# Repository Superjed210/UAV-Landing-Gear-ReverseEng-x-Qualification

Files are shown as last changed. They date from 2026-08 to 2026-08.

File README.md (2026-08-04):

<p align="center">
  <a>
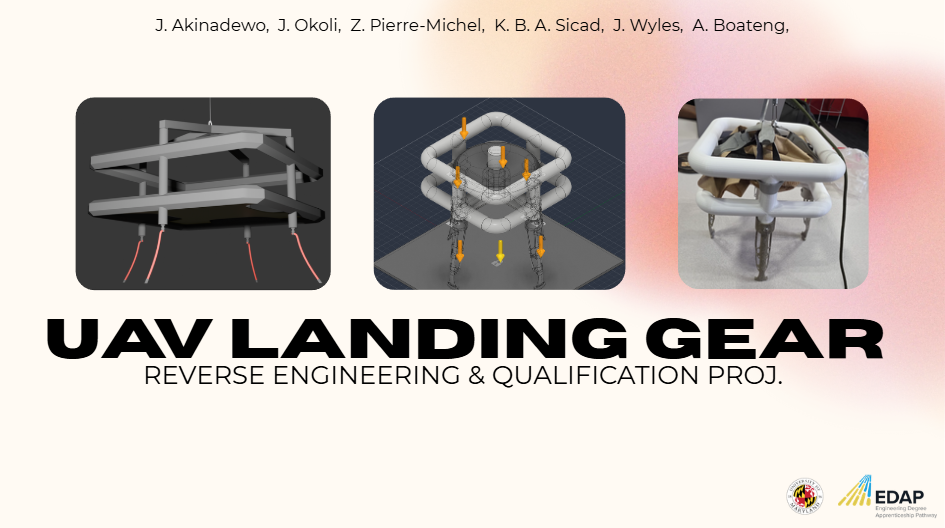
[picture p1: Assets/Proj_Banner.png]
Project Banner
    
  </a>
</p>

> University of Maryland – Department of Materials Science & Engineering
> 
> Summer 2026 - Engineering Design & Additive Manufacturing Research Internship Through *Growth Sector's EDAP Program*

---

## Overview

This repository documents an eight-week engineering research internship completed with the University of Maryland Department of Materials Science & Engineering.

The project followed the complete engineering design process to reverse engineer, digitally reconstruct, optimize, manufacture, and qualify an existing unmanned aerial vehicle (UAV) landing leg. The original component lacked engineering documentation, requiring the team to recover its geometry through metrology, evaluate its structural performance through computational modeling, redesign the component for improved performance and manufacturability, fabricate prototypes using multiple additive manufacturing processes, and validate the final designs through experimental testing.

Rather than focusing on a single engineering discipline, the project integrated reverse engineering, CAD reconstruction, finite element analysis, topology optimization, additive manufacturing, embedded systems, experimental testing, and engineering documentation into one continuous workflow.

---

## Project Background

Mechanical components frequently require replacement long after the original design documentation has been lost or becomes unavailable. In many cases, replacement parts must not only replicate the original geometry but also improve manufacturability, structural performance, and overall efficiency.

To simulate this engineering challenge, the internship used the landing foot from a 2 kg UAV as a case study. The project provided an opportunity to apply the engineering design process from initial inspection through final qualification while maintaining the intended functionality of the original component.

---

## Case Study

The selected engineering challenge involved the qualification of a UAV landing foot intended for a 2kg quadcopter.

The landing gear was expected to:
- Support takeoff and landing
- Perform across multiple landing surfaces including concrete, *(exp: soil, grass, pavement)*
- Protect onboard electronics during impact
- Maintain structural integrity
- Remain economical to manufacture

---

## Engineering Workflow

The complete workflow followed throughout the internship is shown below.

```text
Existing Part
      │
      ▼
Reverse Engineering
      │
      ▼
3D Scanning & Metrology
      │
      ▼
CAD Reconstruction
      │
      ▼
Design Evaluation
      │
      ▼
Topology Optimization
      │
      ▼
Hybrid Design Development
      │
      ▼
Computational Modeling
      │
      ▼
Additive Manufacturing
      │
      ▼
Instrumentation
      │
      ▼
Experimental Testing
      │
      ▼
Qualification
```

Each stage informed the next, allowing engineering decisions to be supported by measured data instead of assumptions.

---

## Reverse Engineering

The project began with reverse engineering an existing UAV landing foot.

Using the Hexagon Romer Absolute Arm, the physical component was digitized into a high-resolution mesh. The resulting scan data was processed in Geomagic Design X to remove imperfections, extract geometric features, and reconstruct an editable CAD model suitable for engineering analysis and manufacturing.

### Primary Tools

- Hexagon Romer Absolute Arm
- Geomagic Design X
- Autodesk Fusion 360

---

## Design and Optimization

Following reconstruction, the landing foot underwent multiple design iterations focused on improving structural performance while minimizing unnecessary material.

Optimization techniques included:

- Static stress analysis
- Shape optimization
- Generative design
- Hybrid optimization

Rather than selecting a purely topology-optimized solution, the final design combined the structural efficiency of topology optimization with the manufacturable geometry of the selected generative design. :contentReference[oaicite:6]{index=6}

---

## Computational Modeling

Finite element analysis was used to evaluate both the original and optimized landing leg designs.

The project progressed from static structural analysis toward dynamic event modeling to better represent transient impact events encountered during landing.

Simulation development included:

- Static stress analysis
- Dynamic event modeling
- Custom nonlinear material definition
- Stress-strain curve development for LPBF 316L stainless steel
- Impact simulations at multiple drop heights

Simulation parameters included:

- Material: 316L Stainless Steel
- Drop heights: 0.15 m, 0.30 m, 0.50 m
- Rigid impact surface
- Gravity enabled
- Structural constraints
- Separated contact conditions

---

## Additive Manufacturing

Multiple additive manufacturing technologies were explored throughout the project.

### PETG Prototype

- Material: PETG
- Process: FDM
- Printer: Bambu Lab X1 Carbon
- Layer Height: 0.16 mm
- Gyroid infill

### Nylon Prototype

- Material: Nylon 12
- Process: Selective Laser Sintering (SLS)

### Metal Prototype

- Material: Stainless Steel
- Process: Laser Powder Bed Fusion (LPBF)

These manufacturing methods allowed comparison between polymer prototypes and production-capable metal components.

---

## Embedded Instrumentation

A custom embedded data acquisition system was developed to characterize landing performance during experimental testing.

Primary components included:

- ESP32 Microcontroller
- ADXL375 High-G Accelerometer
- VL53L1X Time-of-Flight Distance Sensor

The instrumentation system measured:

- Free-fall duration
- Landing velocity
- Peak acceleration
- Bounce height
- Distance from ground
- Structural response during impact

Sensor communication utilized the I²C protocol and calibration routines were implemented prior to testing to reduce measurement error.

## Experimental Testing

Prototype qualification consisted of controlled drop testing.

Testing incorporated:

- Custom drop rig
- Camera tracking
- Embedded sensors
- Multiple landing surfaces
- Graphical data analysis
- Visual inspection

Drop tests were conducted on:
- Concrete
- Soil

using multiple drop heights to evaluate structural behavior under different impact conditions.

## Key Results

Highlights from the project include:

- Successful digital reconstruction of the original UAV landing foot
- Development of a manufacturable hybrid optimized design
- Integration of computational modeling and physical testing
- Custom nonlinear material modeling for 316L stainless steel simulations
- Embedded instrumentation for experimental qualification
- Peak acceleration reduction of approximately **62%** at a 0.5 m drop height
- Maximum yielding reported at approximately **10.1%** during evaluation

---

## Skills Demonstrated

This project demonstrates experience in:

- Engineering Design Process
- Reverse Engineering
- Metrology
- CAD Reconstruction
- Fusion 360
- Geomagic Design X
- Finite Element Analysis
- Dynamic Event Simulation
- Topology Optimization
- Generative Design
- Design for Additive Manufacturing
- Experimental Design
- Data Acquisition
- Sensor Calibration
- ESP32 Embedded Systems
- Engineering Documentation
- Technical Communication

---

## Repository Structure

```text
assets/
data/
docs/
firmware/
models/
references/
presentation/
```

Additional documentation for each engineering phase can be found within the corresponding directories.

---

## Personal Contributions

During this internship, I contributed to multiple phases of the engineering workflow, including CAD reconstruction, computational modeling, design optimization, embedded instrumentation, firmware development, sensor calibration, experimental testing, data analysis, and technical documentation.

This repository serves as a technical record of that work and highlights the interdisciplinary engineering skills developed throughout the internship.

---

## Repository purpose

This repository is intended for educational and professional portfolio purposes.

Some proprietary design files, datasets, or laboratory resources may not be included.

---

## Acknowledgements

This work was completed through the Engineering Design and Additive Manufacturing Program (EDAP) hosted at the University of Maryland Department of Materials Science & Engineering in collaboration with Growth Sector.

Special thanks to the faculty, researchers, graduate students, and fellow interns whose mentorship and collaboration contributed to the success of this project.

---

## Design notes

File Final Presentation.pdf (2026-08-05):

# MSE Drone Leg Qualification

J. Akinadewo, J. Okoli, Z. Pierre-Michel, K. B. A. Sicad, J. Wyles, A. Boateng, and B. Daheu

## Problemstatement

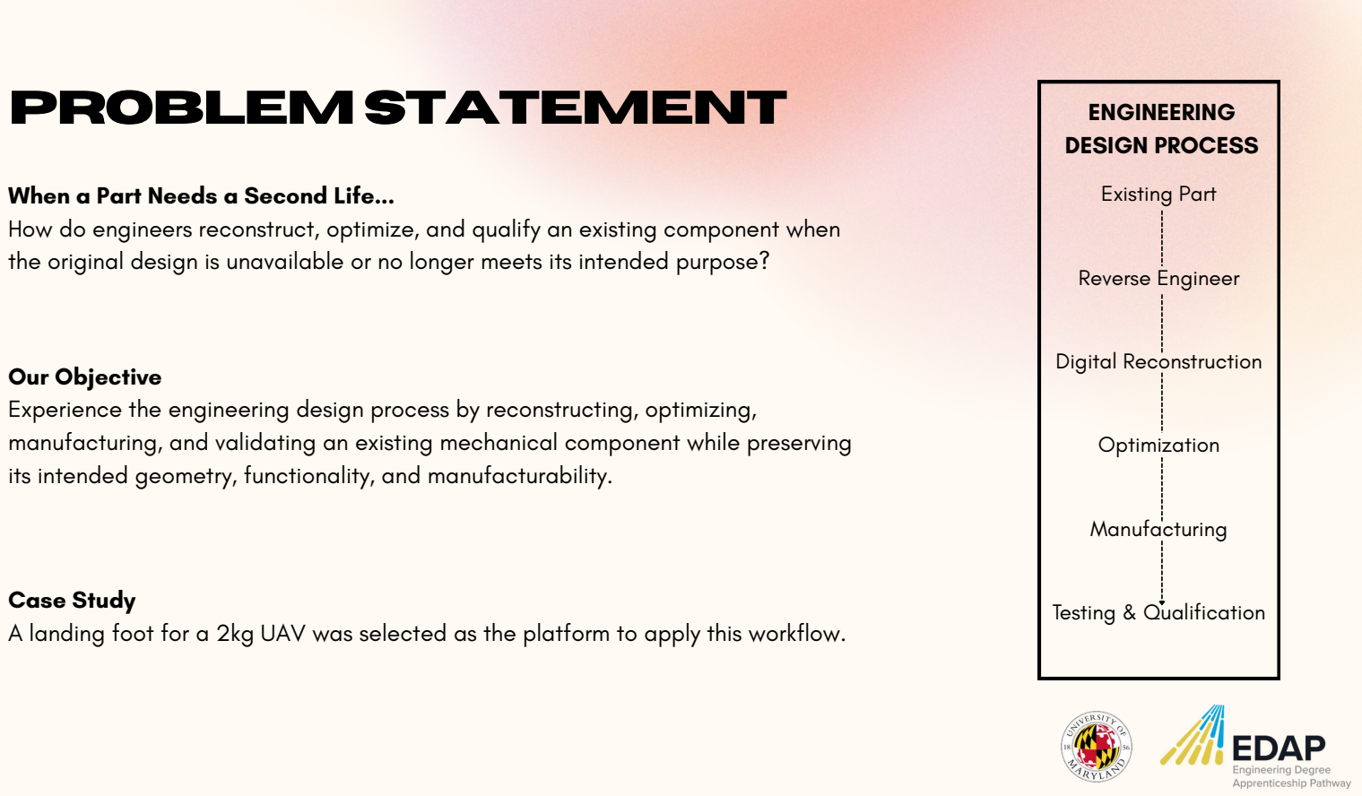
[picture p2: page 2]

Existing Part

Reverse Engineer

Digital Reconstruction

Optimization

Manufacturing

Testing & Qualification

When a Part Needs a Second Life...
How do engineers reconstruct, optimize, and qualify an existing component when the original design is unavailable or no longer meets its intended purpose?

ENGINEERING
DESIGN PROCESS

Our Objective
Experience the engineering design process by reconstructing, optimizing, manufacturing, and validating an existing mechanical component while preserving its intended geometry, functionality, and manufacturability.

Case Study
A landing foot for a 2kg UAV was selected as the platform to apply this workflow.

Concept
Apply the complete engineering design process to a challenge problem involving the reverse engineering & qualification of a UAV landing leg that requires reconstruction, optimization, and manufacturing.

## CASESTUDY

Important Factors
Support takeoff and landing in varied landing conditions (e.g., grass, Soil, Concrete) Ensure onboard packages remain safe on a heavy impact
Economical production while maintaining structural integrity
Achieve through metrology, design, manufacturing, and testing

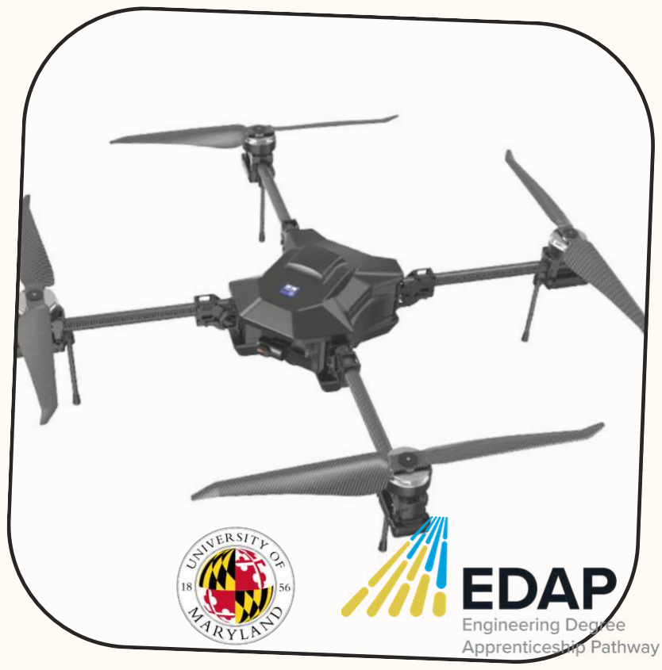
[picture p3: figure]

# Metrology

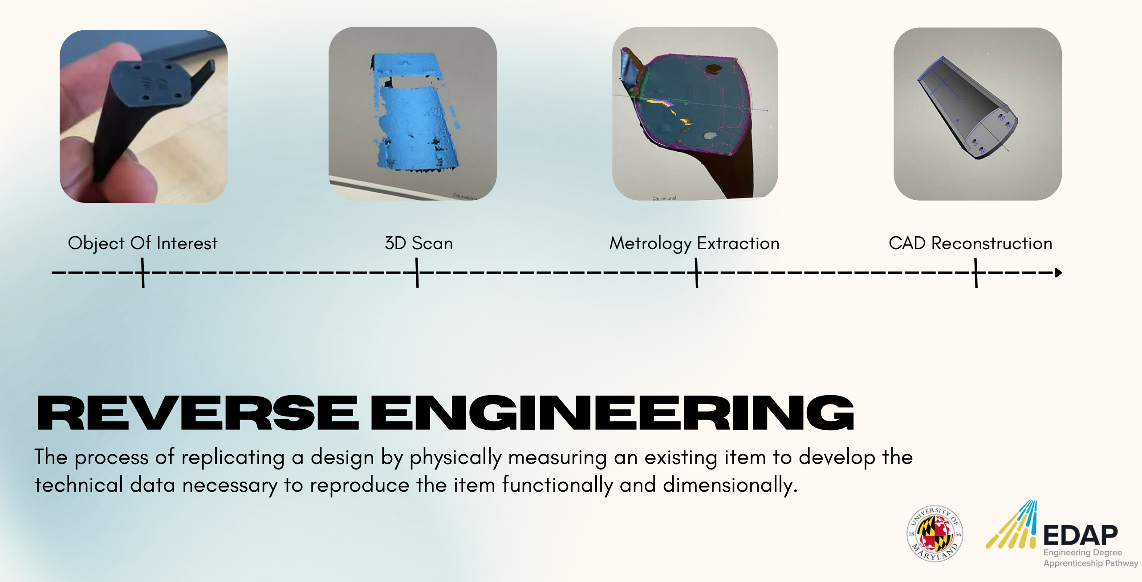
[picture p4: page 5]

Object Of Interest | 3D Scan | Metrology Extraction | CAD Reconstruction

The process of replicating a design by physically measuring an existing item to develop the technical data necessary to reproduce the item functionally and dimensionally.

# ReverseEngineering

## 3DScanning

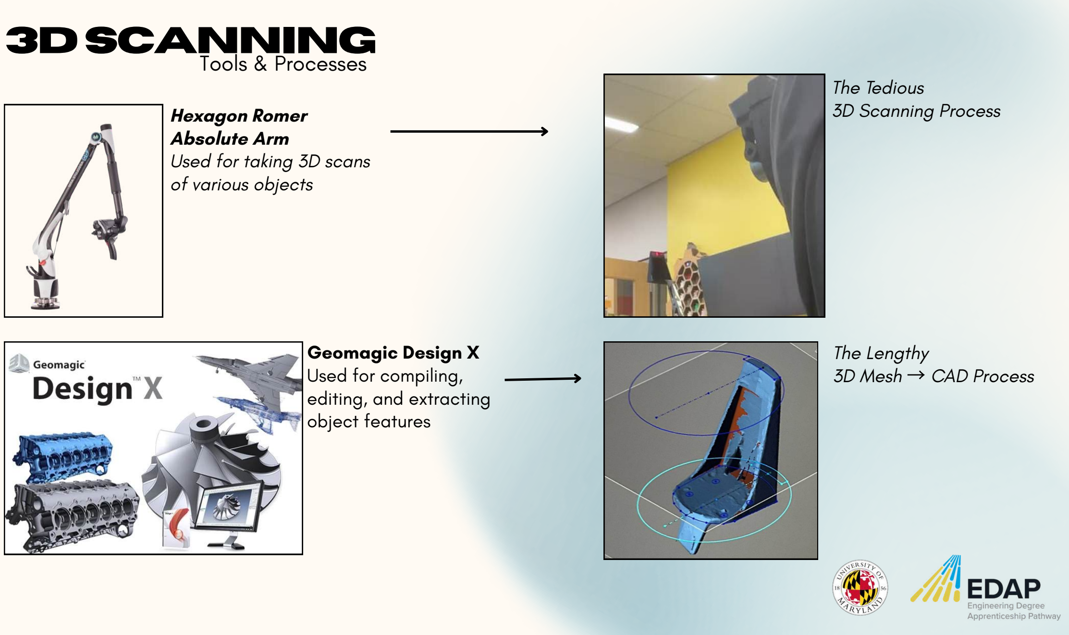
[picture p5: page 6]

Tools & Processes

Hexagon Romer
Absolute Arm
Used for taking 3D scans
of various objects

Geomagic Design X
Used for compiling,
editing, and extracting
object features

The Tedious
3D Scanning Process

The Lengthy
3D Mesh → CAD Process

# Design

## CHassisdesign

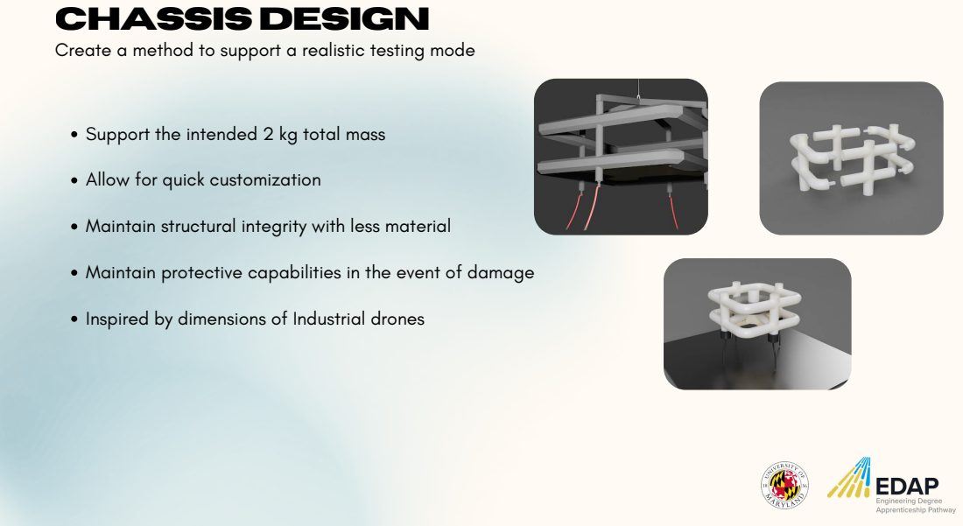
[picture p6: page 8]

Create a method to support a realistic testing mode

Support the intended 2 kg total mass

Allow for quick customization

Maintain structural integrity with less material

Maintain protective capabilities in the event of damage

Inspired by dimensions of Industrial drones

## iterativedesign

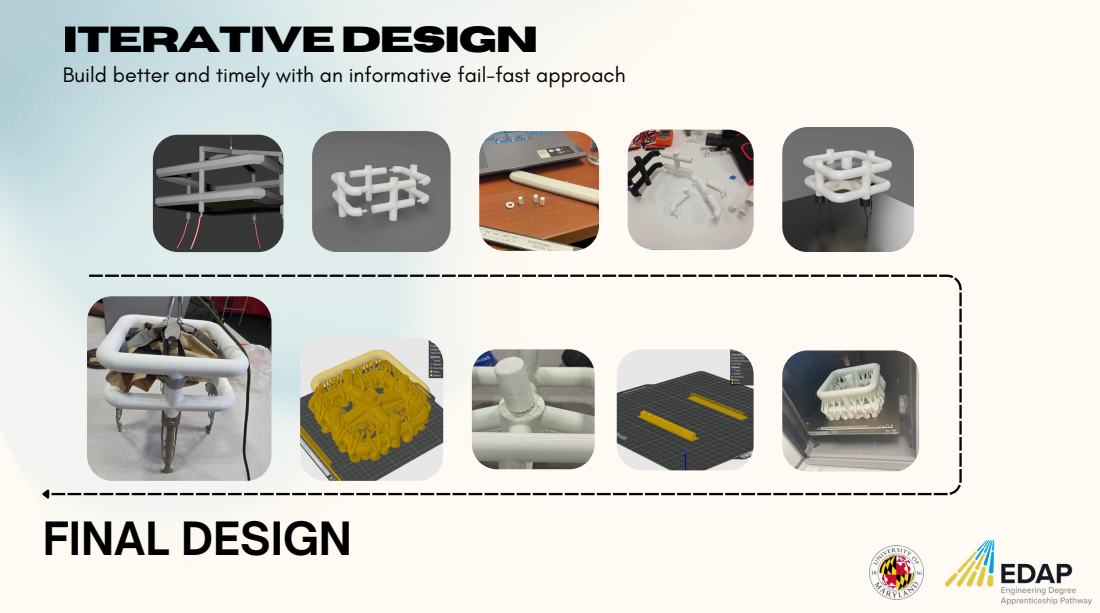
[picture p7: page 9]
FINAL DESIGN

Build better and timely with an informative fail-fast approach

# Design Experimentation

### What is a Charpy Test?

### This is an impact test used in materials

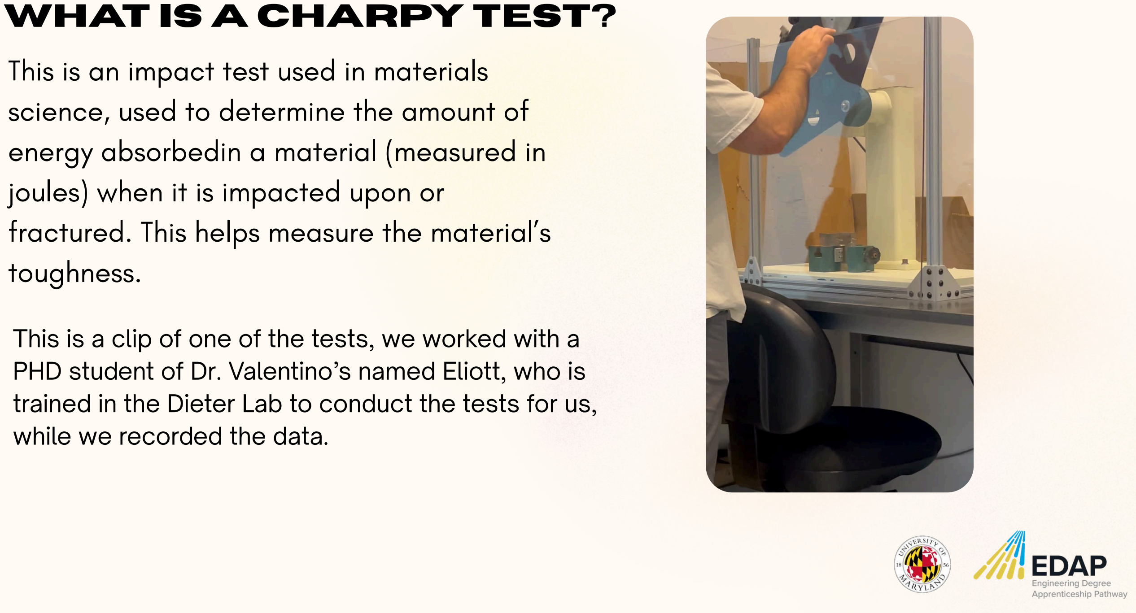
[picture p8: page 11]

### science, used to determine the amount of energy absorbedin a material (measured in joules) when it is impacted upon or fractured. This helps measure the material’

s
toughness.

This is a clip of one of the tests, we worked with a PHD student of Dr. Valentino’s named Eliott, who is trained in the Dieter Lab to conduct the tests for us, while we recorded the data.

## Charpy Impact Test Results

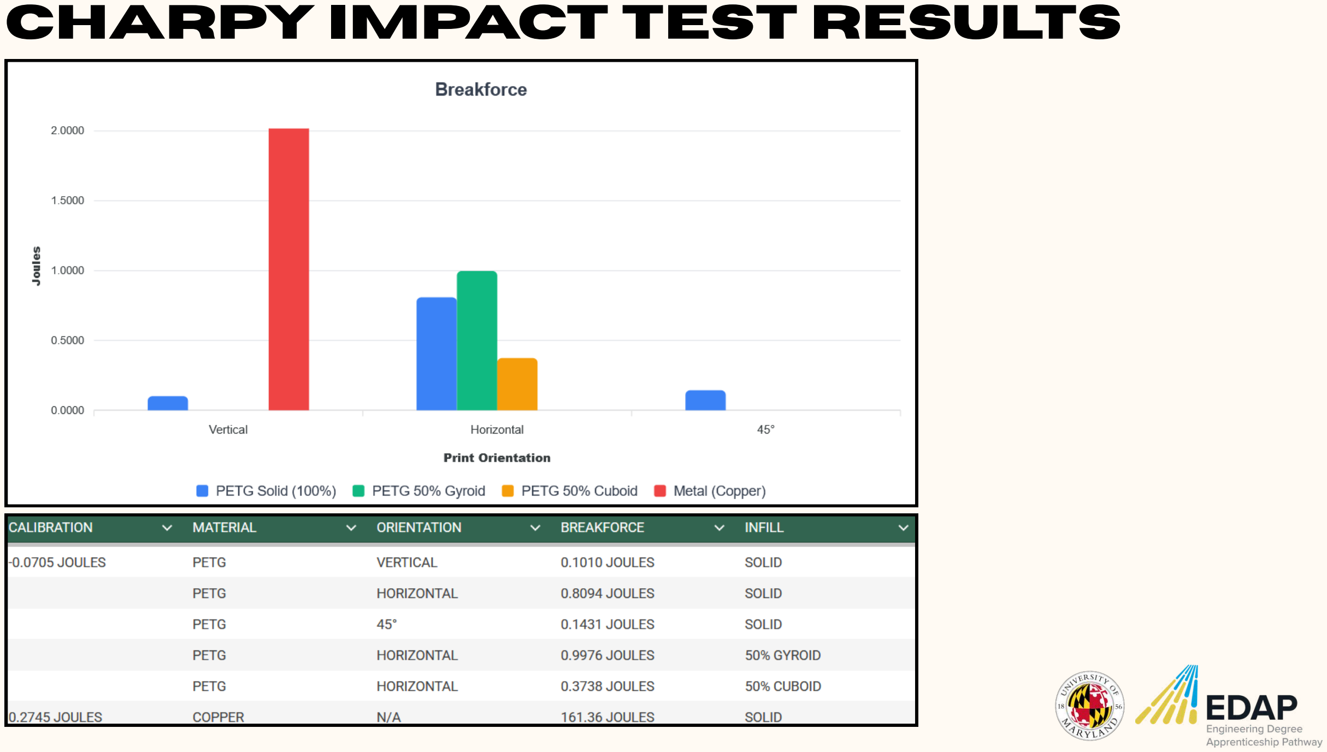
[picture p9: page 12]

## Legdesign

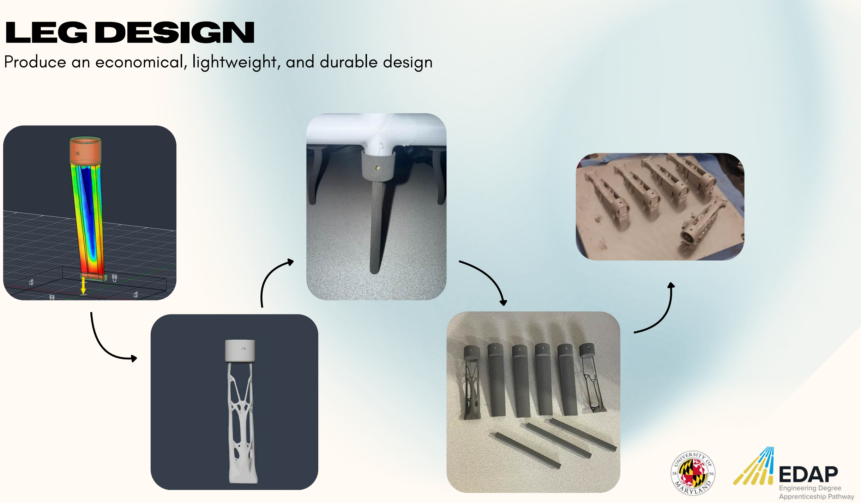
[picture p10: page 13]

Produce an economical, lightweight, and durable design

## ShapeOPtimization

## GenerativeDesign

Identifies the most efficient material distribution under the applied loads and constraints

Generates multiple manufacturable design concepts while preserving critical mounting regions.

## GenerativeDesign

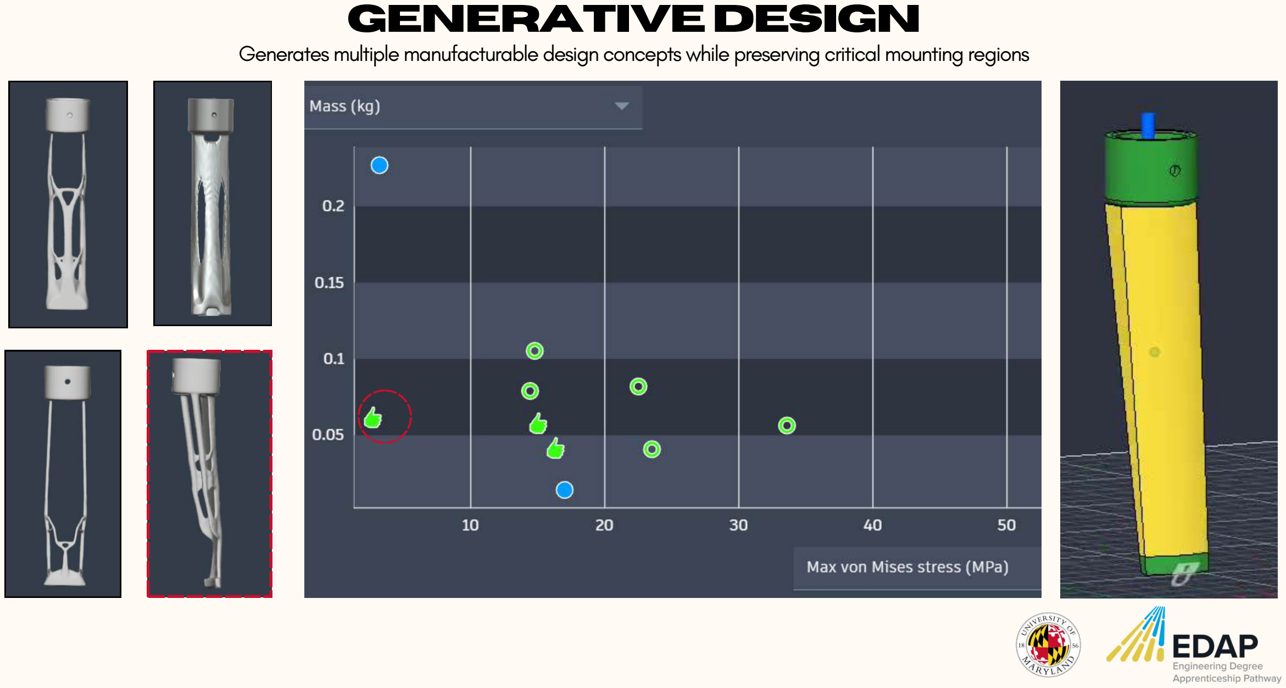
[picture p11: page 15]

Generates multiple manufacturable design concepts while preserving critical mounting regions

## HybridOPtimizedDesign

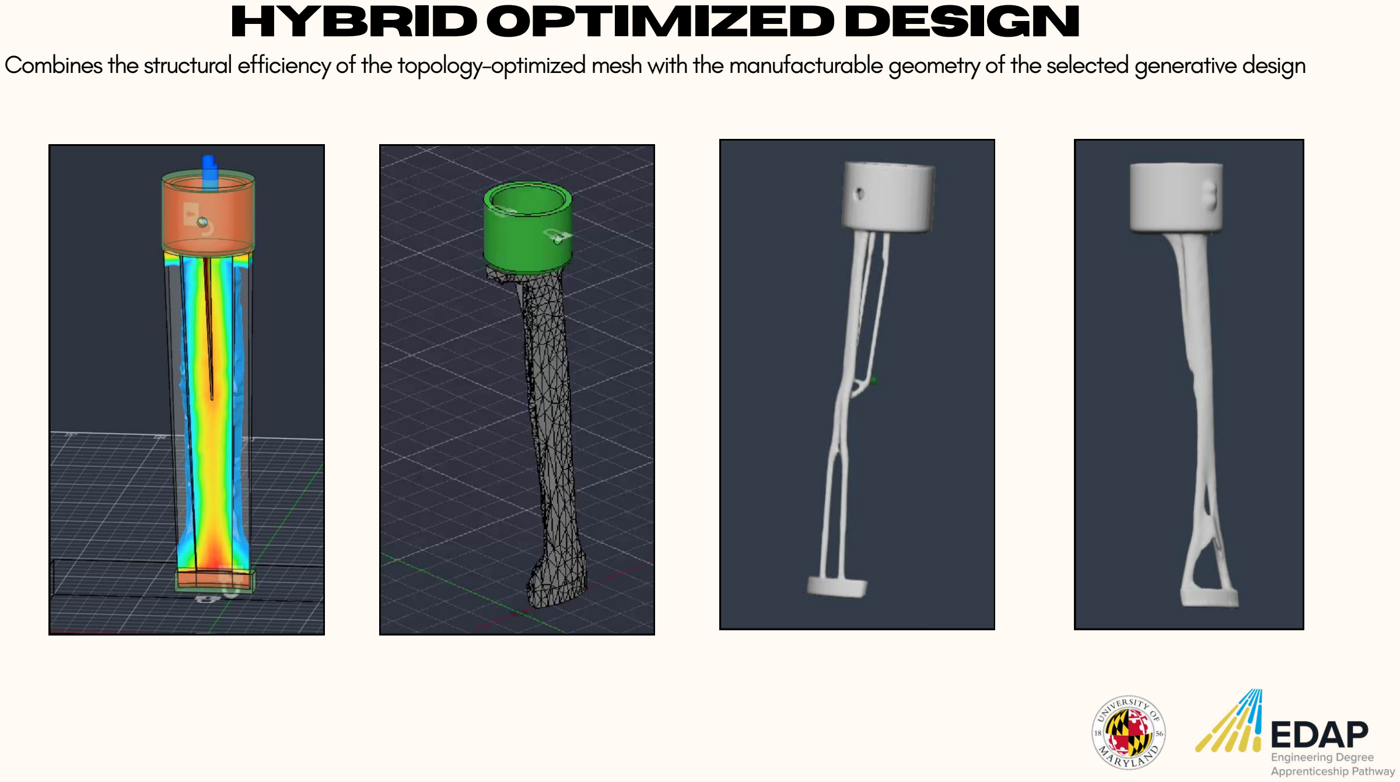
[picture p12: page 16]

Combines the structural efficiency ofthe topology-optimized mesh with the manufacturable geometry ofthe selected generative design

# Computational Modeling

## Staticstressmodeling

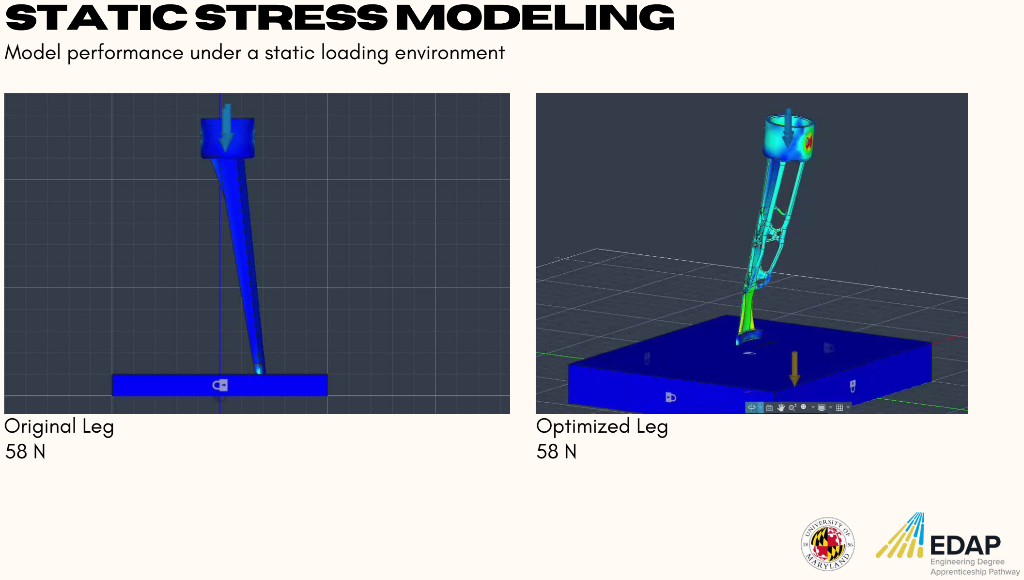
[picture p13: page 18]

Model performance under a static loading environment

Original Leg | Optimized Leg
58 N | 58 N

Dynamic Event | Static Stress
Analyzes short, fast, and violent events like crashes, drops, or hits. | Calculates safe loads, displacement, and stress under steady or slowly applied forces.
Accounts for mass, velocity, acceleration, inertia, and fast-changing contact between parts. | Ignores inertia, momentum, and acceleration because the load changes very little over time.
Requires non-linear stress-strain curve | Does not require stress-strain curve

## Dynamiceventmodeling

Transitioned from static stress analysis to a dynamic event simulation to capture transient force effects

Resolution: Sourced a peer-reviewed research paper containing empirical data detailing the exact stress-strain curves of SLM-printed SS316L.

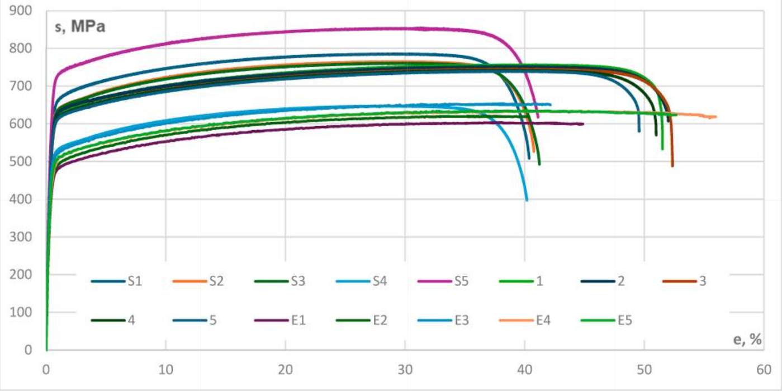
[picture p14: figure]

Sumanariu, Constantin Alex et al.“Comparative Analysis of Mechanical Properties: Conventional vs. Additive Manufacturing for Stainless Steel 316L.” Materials (Basel, Switzerland) vol. 17,19 4808. 29 Sep. 2024, doi:10.3390/ma17194808

## Datamodelingblocks

Autodesk Fusion

’

s default library lacks the non-linear stress-strain curve data required for Stainless Steel 316L impact simulations

## Dataextraction

Digitization

Data Conversion

CustomMaterial

True Strain Formula True Stress Formula

### Material: 316L Stainless Steel Drop Heights: 0.15m, 0.3m, and 0.5m Velocities: 1.72 m/s, 2.43 m/s, and 3.13 m/s

## Impact Surface: Rigid Floor

### Constraints: Structural Constraint

## Contacts: Separated Gravity: Enabled

## Technicalinformation

## Setup

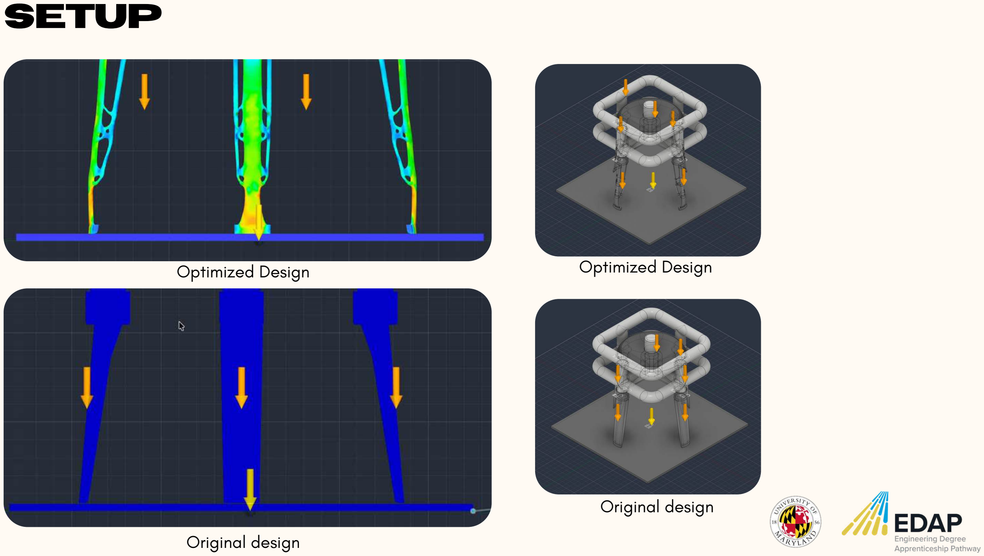
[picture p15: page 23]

Original design

Optimized Design

Original design

Optimized Design

A 62% reduction in Peak acceleration at 0.5 m

## Findings

10.1% Max Yielding

## Findings

# Electronics

## Keymetrics

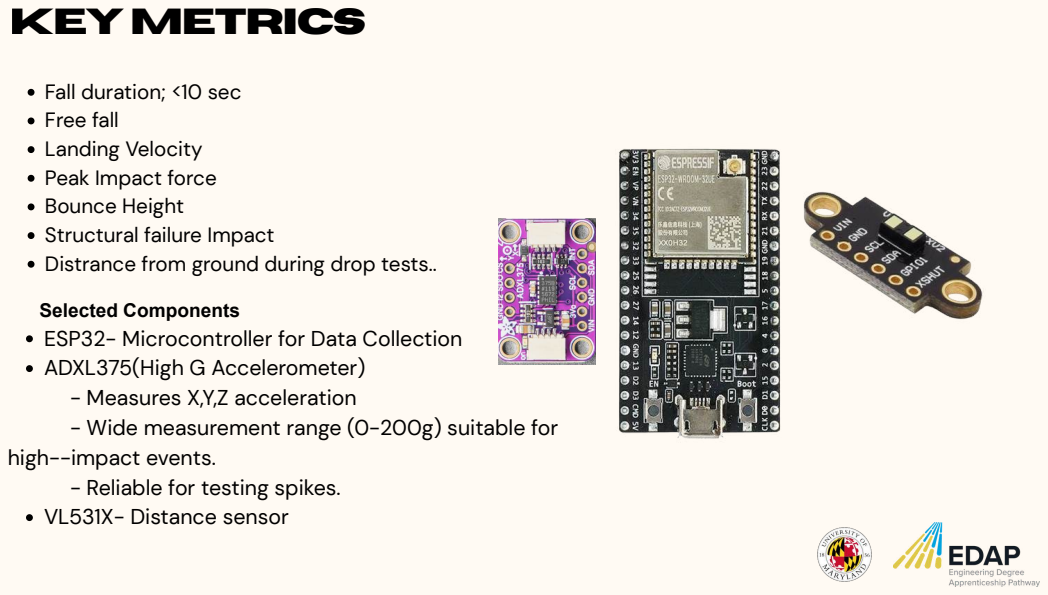
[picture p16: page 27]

Fall duration; <10 sec
Free fall
Landing Velocity
Peak Impact force
Bounce Height
Structural failure Impact
Distrance from ground during drop tests..

Selected Components
ESP32- Microcontroller for Data Collection
ADXL375(High G Accelerometer)
- Measures X,Y,Z acceleration
- Wide measurement range (0-200g) suitable for
high--impact events.
- Reliable for testing spikes.
VL531X- Distance sensor

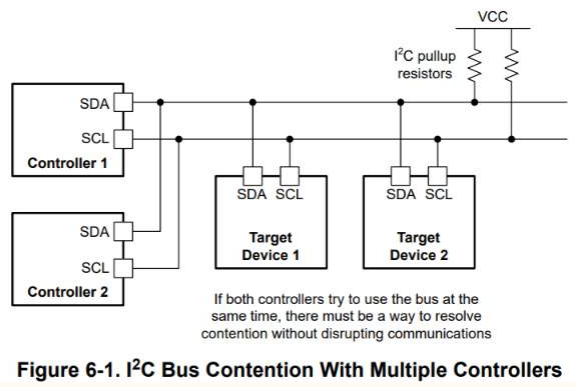
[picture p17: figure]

“3-Axis, ±200 G Digital MEMS Accelerometer.” n.d. Accessed July 30, 2026.

I2C (inter Integrated circuit) is a communication protocol that allows a microcontroller(master) communicate with multiple sensors (slave) using only two signal wires.

WHY we use I2C?
Built into the Arduino <Wire.h> Library
Multiple sensors share the same bread board bus. Uses only two communication wires.
SCL ⟶ Serial Clock synchronization
SDA ⟶ Data Transfer between ESP32 and sensors VIN/VCC ⟶ 3V or 5V
Reliable for real-time sensor measurements

Communication sequence
ESP32
Send Sensor REGISTERS/ADDRESS- Stores 8 bit data Sensor acknowledges (ACK)
Read/Write Register - //writeRegister(), //readRegister() Transfer Data/ Print
STOP

## esp32i2cComm

Sensor Calibration;
To improve mesaurement accurace, sensor offsets were calculated before testing;

Calibration Process

1.Calibrated distance sensor to zero out the baseline distance from the foot to the ground for precise measurements.

2.Calculated multiple stationary readings, Calculated the average X,Y, Z values. 3.Determined offset values using;
Offset = Measured Values - Value Average 4.Applied offsets in software to correct future measurements.

Results: Reduced errors and improved accuracy.

“3-Axis, ±200 G Digital MEMS Accelerometer.” n.d. Accessed July 30, 2026.

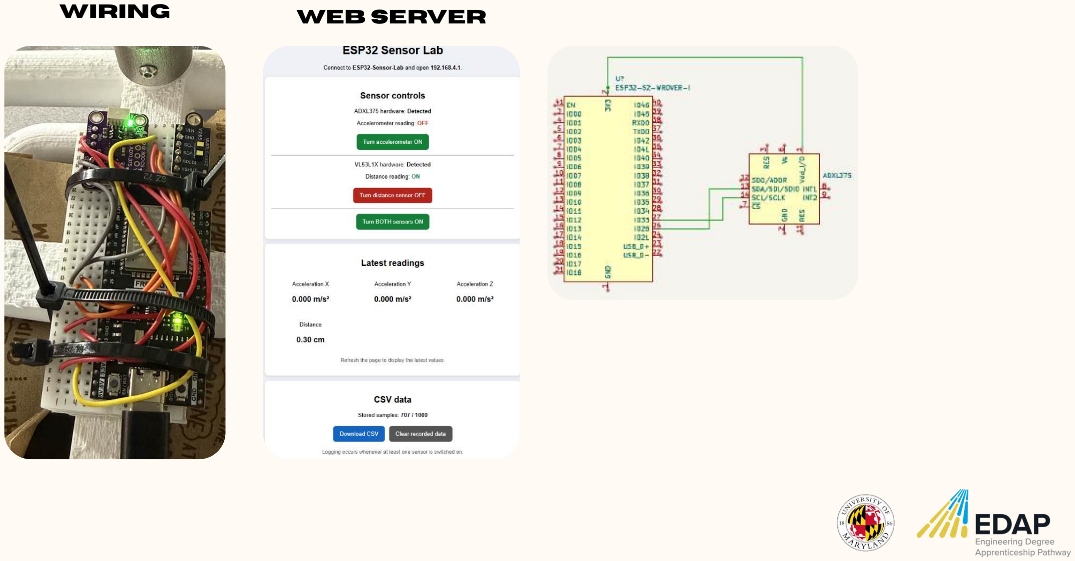
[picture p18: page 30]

Wiring | Web server

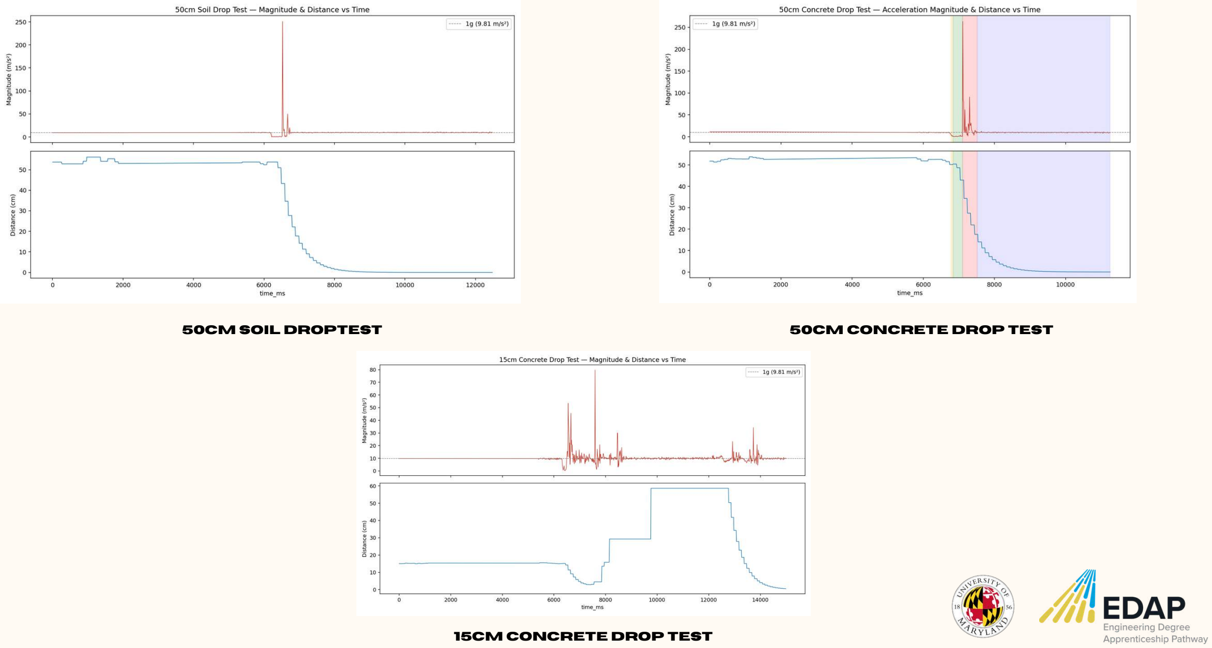
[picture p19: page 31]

50cmsoil droptest | 50cmconcrete drop test

15cmConcrete drop test

# Fabrication

# Rig Fabrication

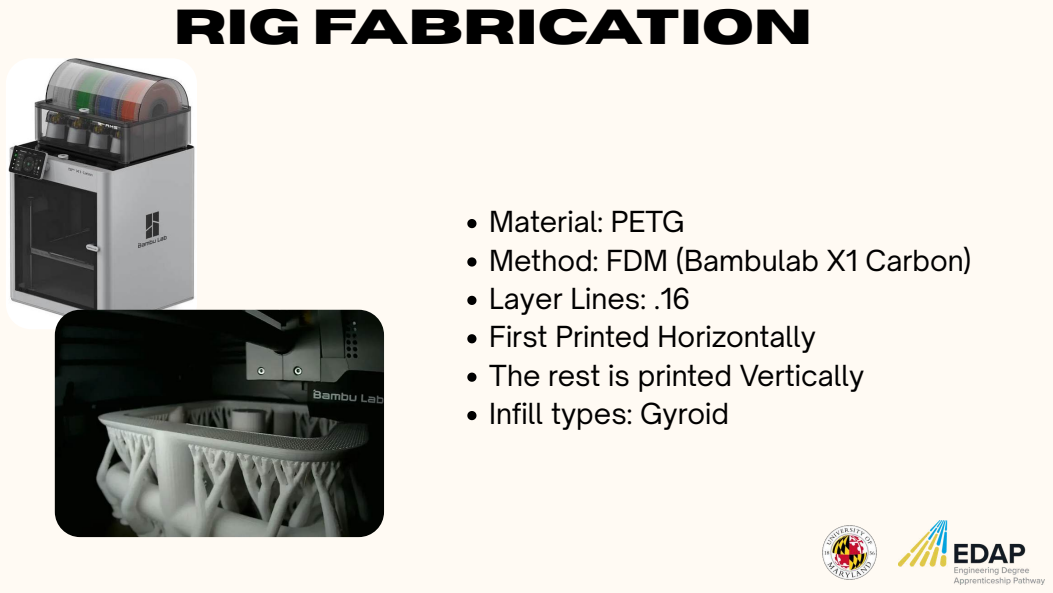
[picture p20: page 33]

Material: PETG
Method: FDM (Bambulab X1 Carbon)
Layer Lines: .16
First Printed Horizontally
The rest is printed Vertically
Infill types: Gyroid

# Nylon Foot Fabrication

## Material: Nylon 12 Method: SLS (Formlabs Fuse) Layer lines: Negligible more isotropic

# Steel Foot Fabrication

## Material: Steel Method: LPBF (EOS gmbh) Layer lines: Negligible more isotropic

# Post Processing

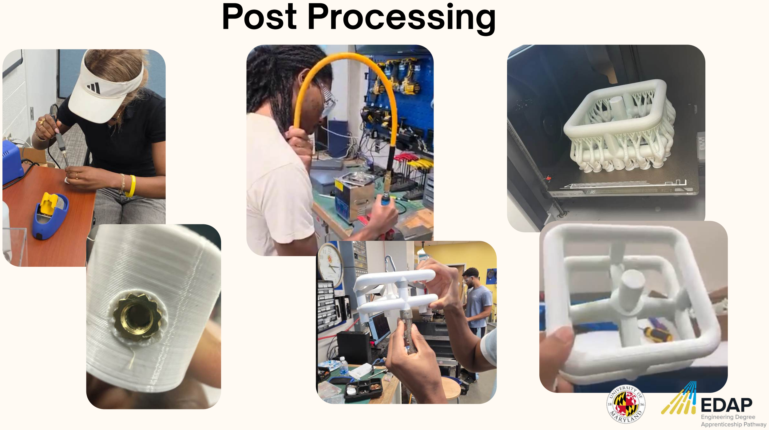
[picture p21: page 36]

# DROP TESTING

# Camera Tracking Electronics: Accelerometer and distance sensor

# Results

# Preparation and Setup

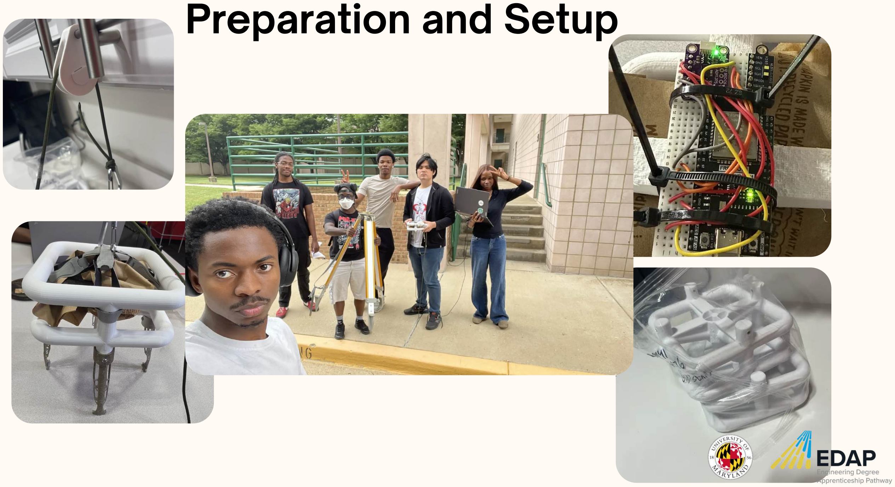
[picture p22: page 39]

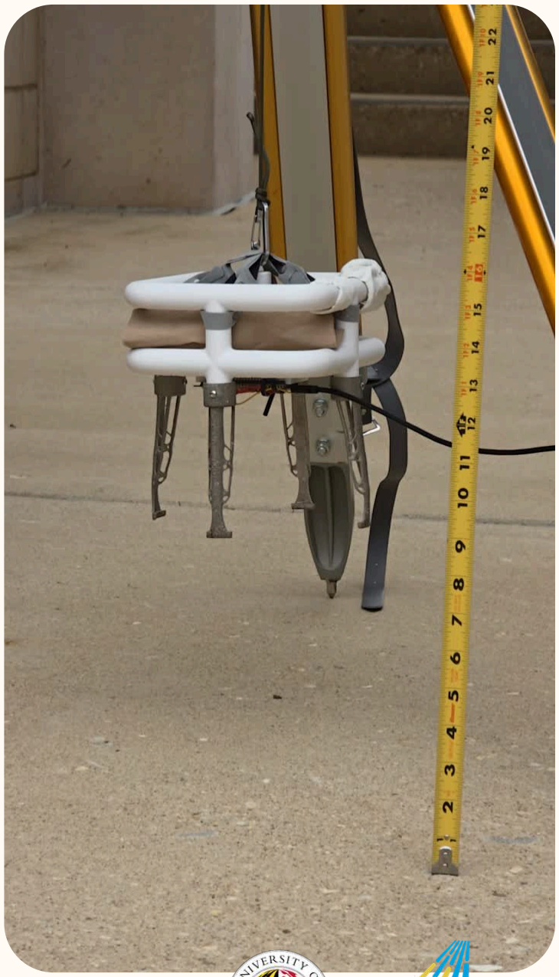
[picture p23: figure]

See in real time how different designs perform

## droptest

Coordinate group preparation

Release a complete model using a pulley

Gather visual and graphical data

Use gathered information to inform a conclusion

## Graphicaldata

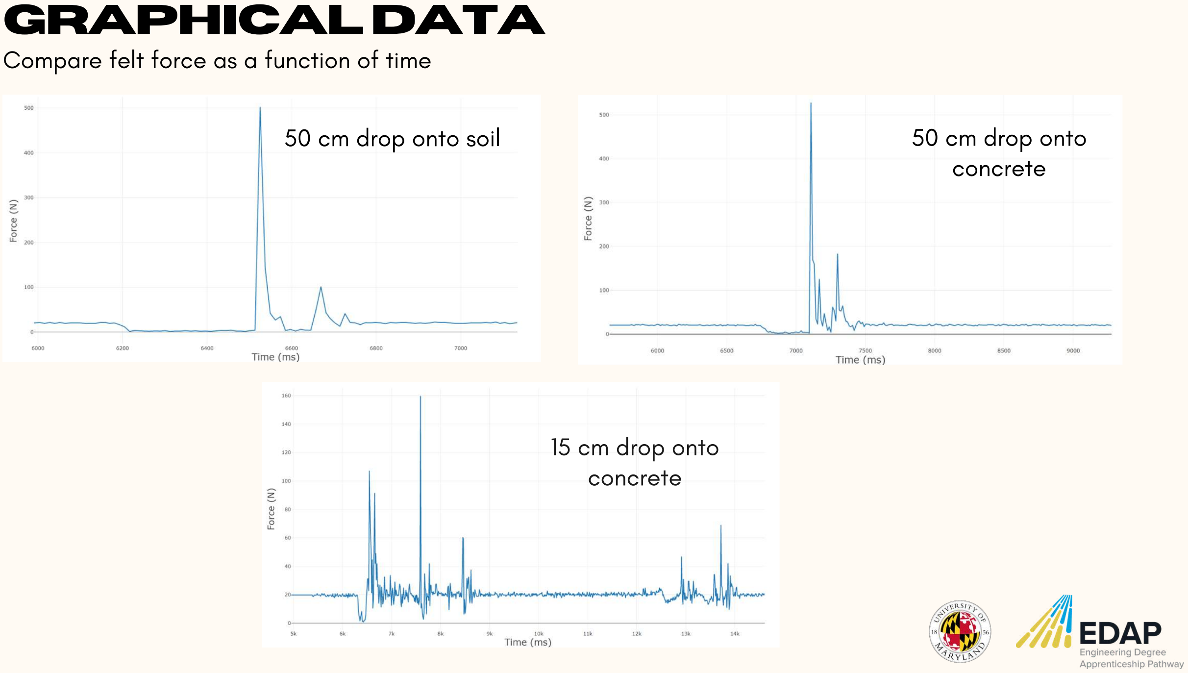
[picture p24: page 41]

Compare felt force as a function of time

50 cm drop onto soil

15 cm drop onto
concrete

50 cm drop onto
concrete

## Visualdata

Compare felt force as a function of time

50 cm drop onto soil

15 cm drop onto
concrete

50 cm drop onto
concrete

# Conclusion

# helpful LINKS

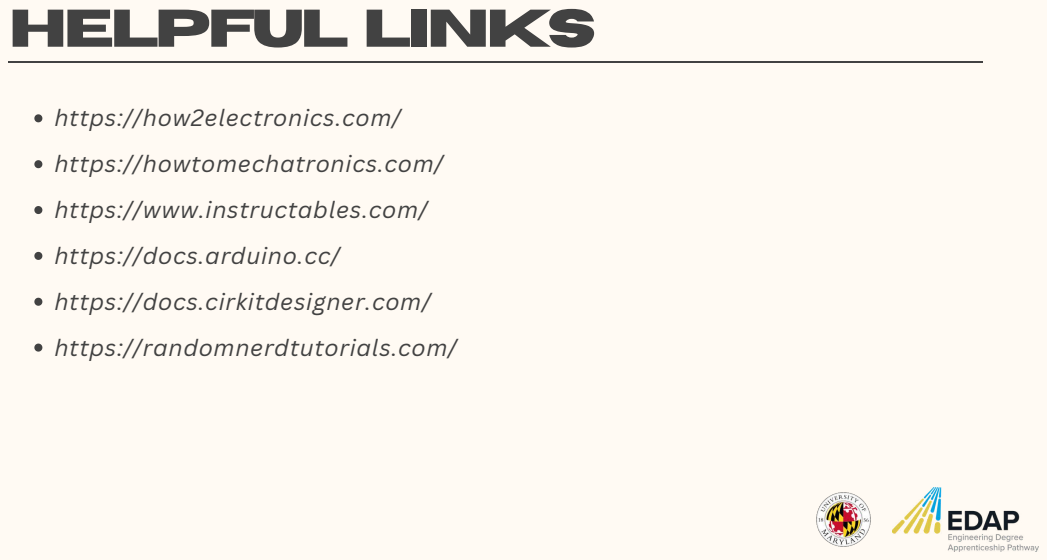
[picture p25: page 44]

https://how2electronics.com/
https://howtomechatronics.com/
https://www.instructables.com/
https://docs.arduino.cc/
https://docs.cirkitdesigner.com/
https://randomnerdtutorials.com/

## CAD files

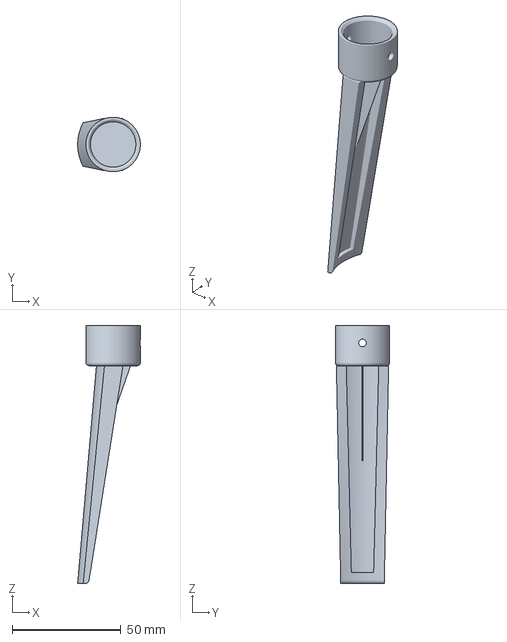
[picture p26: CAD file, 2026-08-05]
3D Models/Reinforced_Reference_Model.3mf
28.8 x 25.0 x 118.5 mm

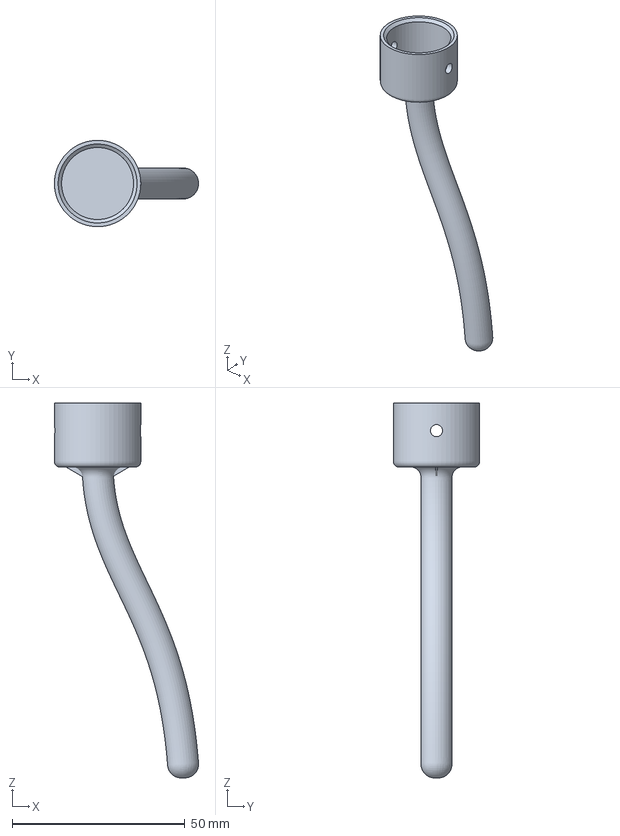
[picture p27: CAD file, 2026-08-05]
3D Models/spring-inspired-leg.3mf
41.7 x 25.0 x 108.5 mm

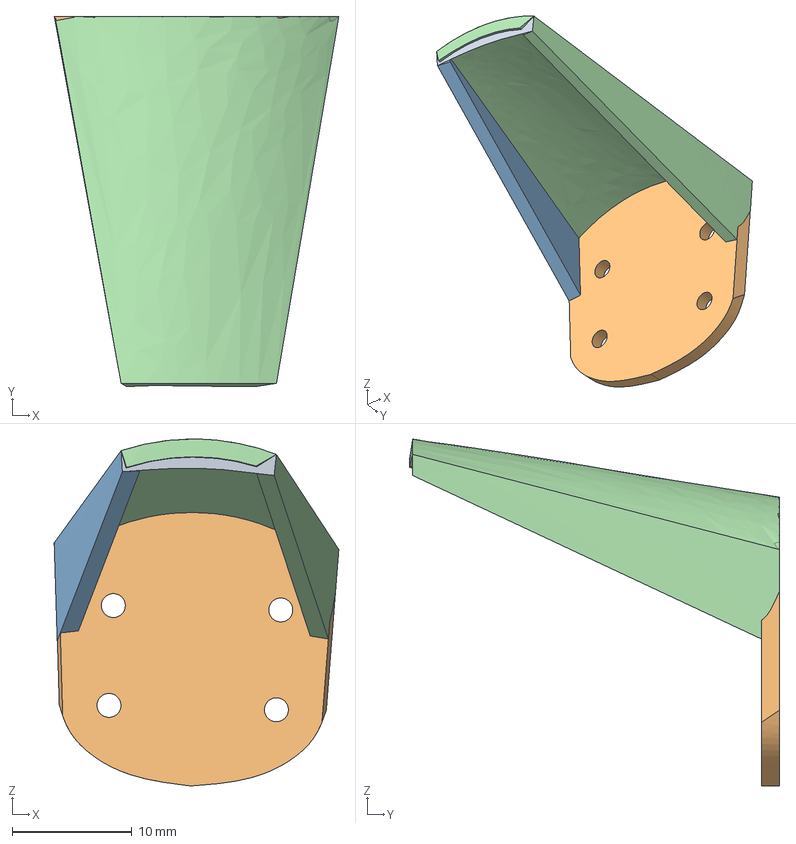
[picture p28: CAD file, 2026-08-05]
3D Models/Original_UAV_Landing_Leg.stp
23.8 x 30.9 x 29.0 mm

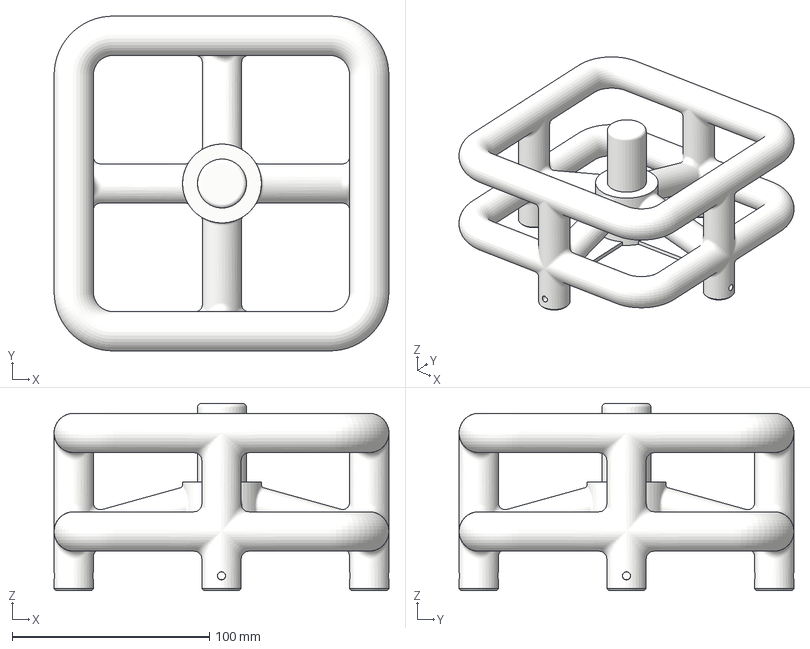
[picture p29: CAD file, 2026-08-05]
3D Models/Test_Rig.3mf
170.0 x 170.0 x 95.0 mm

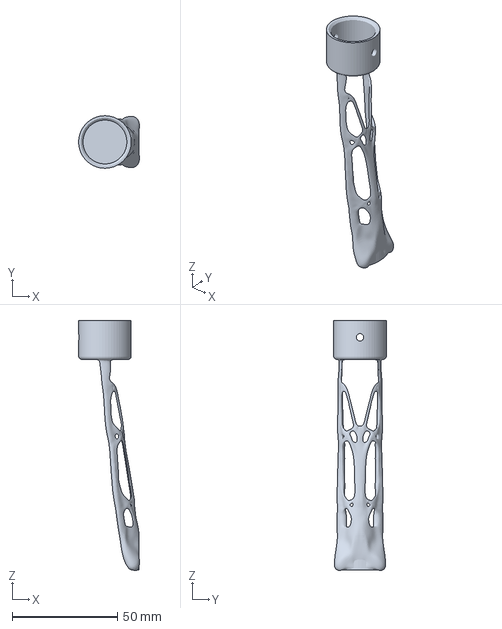
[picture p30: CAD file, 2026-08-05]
3D Models/Iteration_01_Dual_Strut.3mf
28.9 x 25.0 x 118.8 mm

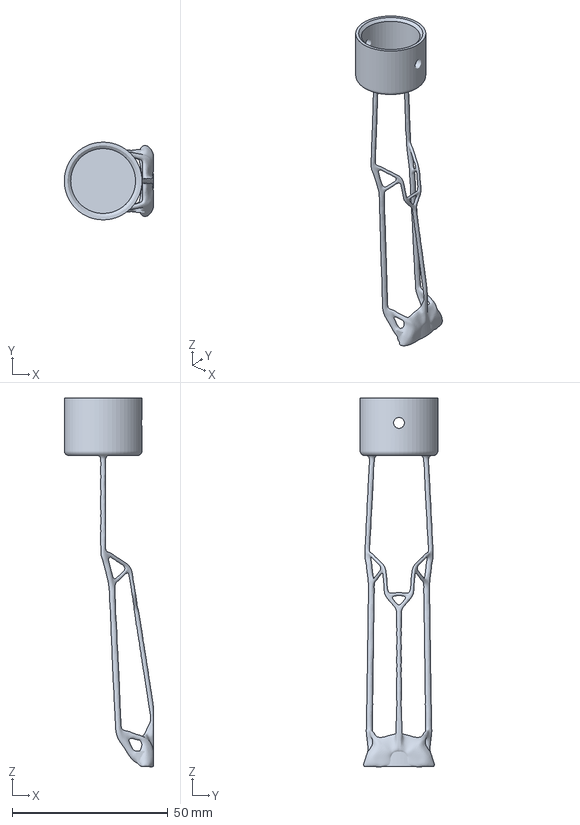
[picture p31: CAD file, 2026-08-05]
3D Models/Iteration_02_Lightweight_Dual_Strut.3mf
28.8 x 25.0 x 118.6 mm

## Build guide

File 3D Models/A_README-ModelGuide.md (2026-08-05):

# 3D Models

This directory contains the CAD models developed and evaluated throughout the reverse engineering, optimization, and testing phases of this project.

The models illustrate the progression from the reconstructed baseline geometry to multiple optimization concepts and the final design selected for manufacturing and testing.

---

## Original UAV Landing Leg
<p align="left">
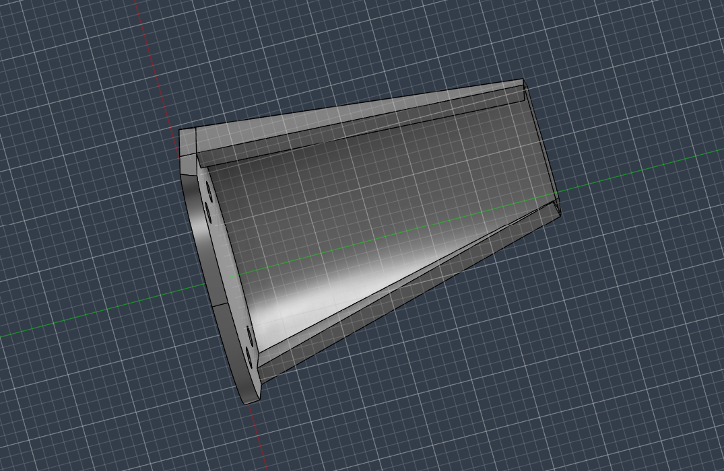
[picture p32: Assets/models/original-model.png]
  
</p>

```
Original_UAV_Landing_Leg.stp
```

This model represents the reconstructed baseline geometry derived from the reverse-engineered landing leg.

Compared to the scanned component, this version includes slight geometric refinements that improved manufacturability and structural consistency while preserving the overall function and appearance of the original design.

This model served as the engineering reference for all subsequent simulations and optimization studies.

**Purpose**

- Baseline CAD model
- Reference geometry
- Simulation comparison
- Starting point for optimization

---

## Reinforced Reference Model
<p align="left">
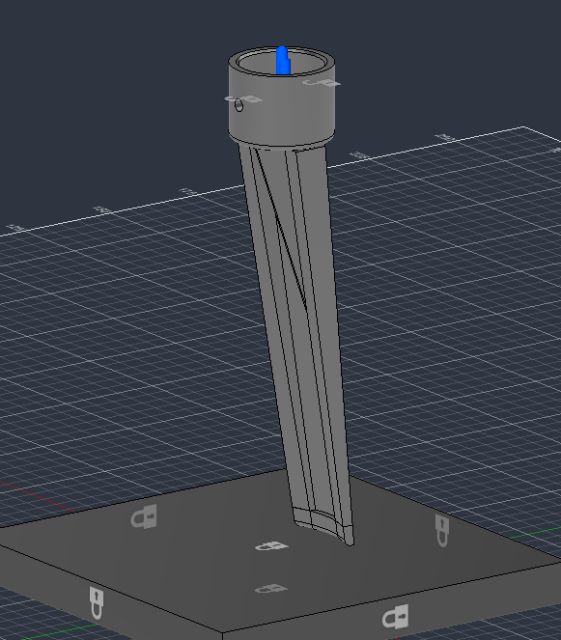
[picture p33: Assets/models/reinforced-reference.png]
  
</p>

```
Reinforced_Reference_Model.3mf
```

This model is an elongated and structurally reinforced version of the reconstructed landing leg.

Additional material was introduced to improve stiffness and create a stronger baseline before applying computational optimization techniques.

Although this was not the final manufactured design, it provided an important comparison against later lightweight concepts.

**Purpose**

- Strengthened reference design
- Initial simulation model
- Baseline for optimization studies

---

### Spring-Inspired Landing Leg

```
Spring_Inspired_Leg.3mf
```

<p align="left">
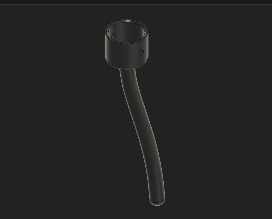
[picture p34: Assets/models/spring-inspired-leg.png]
  
</p>

This concept was developed as a hand-designed exploration of an alternative approach to UAV landing gear. Rather than optimizing an existing geometry, the design reimagines the landing leg as a compliant structure capable of behaving similarly to a spring.

The inspiration came from both biological systems and compliant mechanical structures, particularly the way insect legs deform during landing to absorb and redistribute impact energy. The continuous curved geometry was intended to encourage controlled elastic deformation, allowing the leg to flex under load before returning toward its original shape.

Unlike the topology and generative design models included in this repository, this concept was created manually as an engineering thought experiment. It was used to investigate how geometry alone could contribute to energy absorption and impact mitigation without relying solely on additional material or increased stiffness.

**Design Inspiration**

- Biological locomotion
- Insect leg mechanics
- Compliant mechanisms
- Spring-like energy absorption
- Biomimetic engineering

## Generative_Design

Several computationally generated concepts were explored during the optimization phase.

These models were produced using Fusion 360 Generative Design under identical loading conditions but represent different stages of the design exploration process.

---

### Iteration 01 — Dual-Strut Concept
<p align="left">
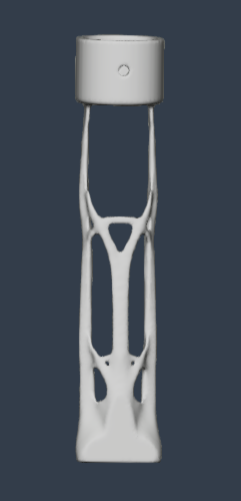
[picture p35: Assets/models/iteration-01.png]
  
</p>

```
Iteration_01_Dual_Strut.3mf
```

This early generative design concept features two primary structural members connecting the landing foot to the upper mounting interface.

The design demonstrated significant weight reduction while maintaining the required load path.

Although structurally interesting, it was retained only as an intermediate design study.

---

### Iteration 02 — Lightweight Dual-Strut Concept
<p align="left">
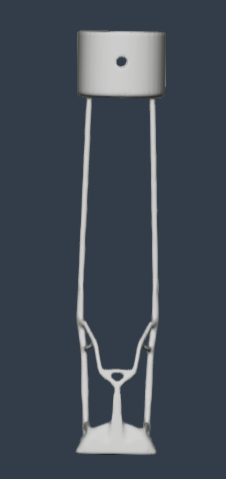
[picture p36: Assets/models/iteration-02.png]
  
</p>

```
Iteration_02_Lightweight_Dual_Strut.3mf
```

This model is a more aggressively optimized derivative of the previous dual-strut concept.

Material removal produced an even lighter structure with thinner supporting members.

While this iteration demonstrated the capabilities of generative design, it was ultimately considered too lightweight for prototype manufacturing and served primarily as a comparison during design evaluation.

---

## Final Design
<p align="left">
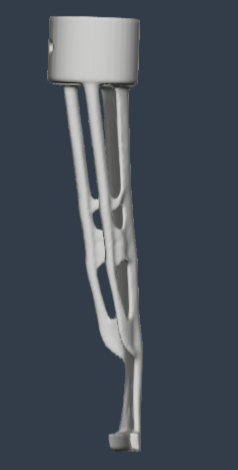
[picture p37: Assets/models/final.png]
  
</p>

```
Final_Hybrid_Design.3mf
```

This model represents the final optimized geometry selected for manufacturing and testing.

The design was generated using:

- Fixed constraint applied at the upper mounting interface
- Load applied from the landing foot upward toward the mounting interface

This configuration reflects the primary structural loading path used during the optimization study.

This model was selected as the final engineering solution and served as the basis for additive manufacturing and experimental qualification.

---

## Drop Test Rig
<p align="left">
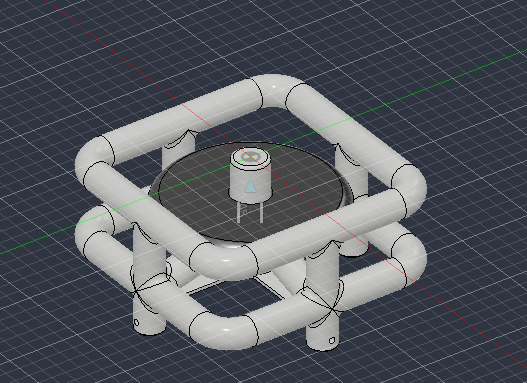
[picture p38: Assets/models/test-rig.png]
  
</p>

```
Drop_Test_Rig.3mf
```

The drop test rig was designed to provide a repeatable experimental platform for evaluating the performance of the UAV landing legs under controlled impact conditions.

The rig securely mounted the landing leg assemblies while maintaining consistent alignment throughout testing.

This fixture enabled controlled drop testing using multiple landing surfaces and supported integration with embedded instrumentation, including the ESP32 microcontroller, ADXL375 accelerometer, and VL53L1X time-of-flight sensor.

The rig ensured that differences observed during testing resulted from the landing leg designs rather than inconsistencies in the experimental setup.

**Purpose**

- Mount landing legs
- Repeatable testing
- Sensor integration
- Controlled impact evaluation
- Experimental validation

---

# Notes

Only the **Final Hybrid Design** was selected for metal fabrication and experimental qualification.

The remaining generative design models are included to document the engineering design process and illustrate the progression of computational optimization throughout the project.

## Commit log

2026-08-04 Revise README for UAV Landing Leg Project
    Updated the README to reflect the project title and provide detailed information about the internship, engineering workflow, and contributions.
2026-08-04 Update and rename file.md to Prototype-Guide.md
2026-08-04 Update Model-Guide with images and descriptions
    Added images and descriptions for various UAV landing leg models and iterations.
2026-08-05 Add Spring-Inspired Landing Leg section to Model Guide
    Added a section on Spring-Inspired Landing Leg, detailing its design inspiration and engineering concepts.
2026-08-05 Rename Screenshot 2026-08-04 200102.png to spring-inspired-leg.png
2026-08-05 Change image alignment to left and adjust width
    Updated image alignment and size for spring-inspired leg model.
